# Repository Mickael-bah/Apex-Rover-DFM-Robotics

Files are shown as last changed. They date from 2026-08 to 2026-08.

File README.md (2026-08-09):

# Apex Rover — DFM & Robotics Engineering Project
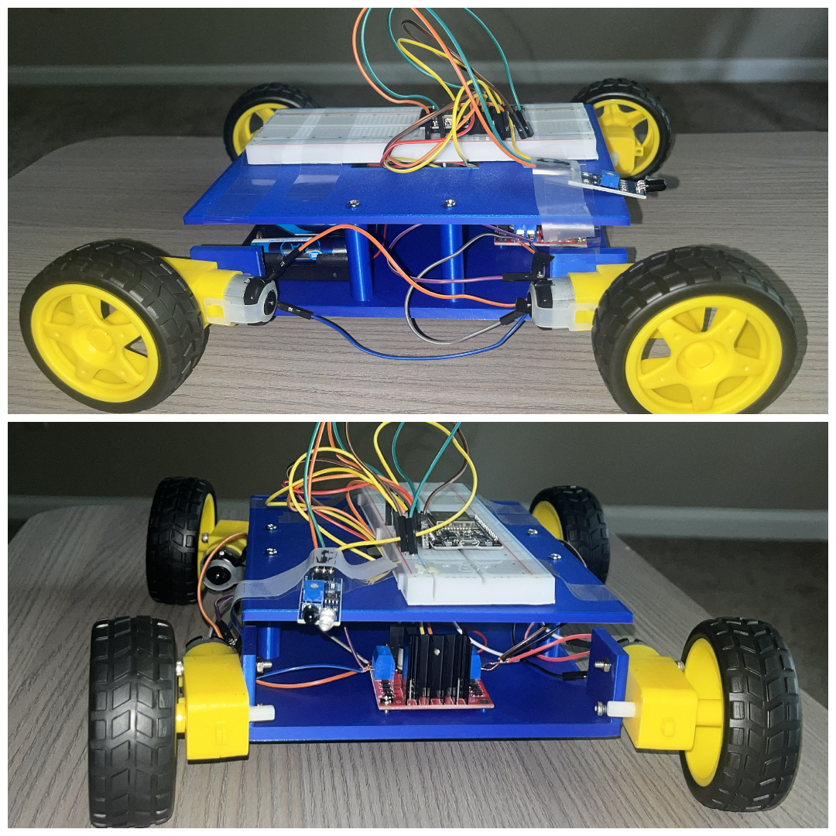
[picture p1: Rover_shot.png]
Apex Rover


https://github.com/user-attachments/assets/dc40459c-ff90-4590-9382-41a43c7b37aa

A custom 4WD robotic rover developed as a hands-on Design for Manufacturing (DFM), mechanical design, fabrication, electronics, and embedded robotics project.

## Project Overview

The Apex Rover is a 4WD skid-steer robotic vehicle built around a dual-deck 3D-printed chassis.

The rover has two operating modes:

- Wi-Fi manual control through an ESP32-hosted web interface
- Autonomous obstacle avoidance using infrared sensing

The main goal of this project was to experience the complete engineering process from CAD design to physical manufacturing, testing, and redesign.

## Engineering Objectives

This project was developed to gain practical experience in:

- Mechanical CAD design
- Design for Manufacturing (DFM)
- FDM 3D printing
- Engineering tolerances
- Fastener and joint design
- Mechanical assembly
- Electrical system integration
- ESP32 development
- Embedded C++
- Robotics control
- Physical prototype testing
- Engineering iteration

The primary objective was not simply to build a working rover, but to understand how a digital design behaves when converted into a physical manufactured prototype.

## Mechanical Design

The rover uses a two-level chassis architecture.

The lower chassis supports:

- Four TT gearbox motors
- Motor drive hardware
- Battery system
- High-current wiring

The upper deck supports:

- ESP32 controller
- Breadboard
- IR sensing hardware
- Control wiring

### Main Dimensions

| Parameter | Specification |
| --- | --- |
| Chassis footprint | 180 x 140 mm |
| Upper deck thickness | 3.5 mm |
| Deck separation | 40 mm |
| Fastener system | M3 |
| FDM infill | 20% gyroid |
| Primary materials | PLA / PETG |

## Design for Manufacturing

The chassis was designed specifically for FDM 3D printing.

Important DFM considerations included:

### Fastener Hole Tolerancing

M3 clearance holes were modeled at approximately 3.4 mm rather than the nominal 3.0 mm bolt diameter.

This provides clearance for the M3 fastener and accounts for the dimensional behavior of FDM printing.

### Structural Pillars

The lower chassis incorporates integrated 40 mm pillars supporting the upper deck.

This reduces the number of separate structural components and simplifies assembly.

### Cable Routing

A 60 x 40 mm cable pass-through opening was incorporated into the upper deck.

This allows motor and power wiring to pass between the two decks while keeping the wiring organized.

## V1 Prototype and Engineering Lessons

The physical prototype revealed several design considerations that were not fully apparent from CAD alone.

The most important observation was minor rotational movement at the pillar joints during high-torque skid turns.

This demonstrated the importance of positive mechanical retention in dynamically loaded joints.

The prototype also demonstrated the difference between clearance holes and threaded holes. A 3.4 mm M3 clearance hole allows a bolt to pass through, but it cannot provide a threaded connection by itself.

These observations were used to develop the V2 design.

## V1 to V2 Improvements

| V1 Observation | V2 Design Response |
| --- | --- |
| Pillar joint wobble | M3 heat-set brass inserts |
| Clearance holes cannot provide direct M3 threading | Dedicated self-tapping hole geometry |
| Nut accessibility | Recessed hex-nut pockets |
| Shared motor and logic power architecture | Dedicated 5 V logic regulator |

## Electronics

The rover is controlled by an ESP32.

Main components include:

- ESP32 NodeMCU
- L298N dual H-bridge motor driver
- Four TT gearbox motors
- IR obstacle detection system
- 6 x AA battery enclosure
- Breadboard
- M3 structural hardware

### ESP32 Motor Control

| ESP32 GPIO | Function |
| --- | --- |
| GPIO 26 | Left motor forward |
| GPIO 27 | Left motor reverse |
| GPIO 14 | Right motor forward |
| GPIO 12 | Right motor reverse |
| GPIO 33 | IR obstacle sensor input |

## Software

The firmware is written in C++ for the ESP32.

The rover hosts a local web interface through the ESP32 Wi-Fi access point.

Manual control uses HTTP endpoints for forward, backward, left, right, stop, automatic mode, and manual mode.

Autonomous operation uses a non-blocking state machine based on millis().

Major autonomous states include:

- DRIVING
- AVOID_STOPPING
- AVOID_REVERSING
- AVOID_PAUSING
- AVOID_TURNING
- PATROL_TURNING

### 🎮 Web Controller Interface

ESP32 Web Gamepad Interface

The ESP32 hosts an onboard HTTP REST server serving a responsive, dark-mode HTML5/CSS gamepad interface. It uses non-blocking JavaScript `fetch()` calls tied to touch events for zero-latency **Hold-to-Drive** safety control in landscape orientation.

## Manufacturing Workflow

The prototype followed this general engineering workflow:

1. Define requirements
2. Develop chassis architecture
3. Create CAD geometry
4. Apply DFM considerations
5. Manufacture the 3D-printed components
6. Assemble the mechanical system
7. Install electronics
8. Route and connect wiring
9. Upload and verify firmware
10. Test the physical prototype
11. Identify design limitations
12. Develop V2 improvements

## Repository Contents

- `Apex_Rover_DFM_Report_MB.pdf` - Complete DFM and technical report
- `apex_rover.ino` - ESP32 firmware
- `lower_chassis.step` - Lower chassis CAD model
- `lower_chassis.stl` - Lower chassis 3D-print file
- `top_deck.step` - Top deck CAD model
- `top_deck.stl` - Top deck 3D-print file
- `2D_technical_drawing.png` - Dimensioned technical drawing

## Lessons Learned

This project demonstrated that DFM is an iterative engineering process.

The workflow is not simply:

CAD -> Print -> Done

Instead, the physical prototype creates information that can be used to improve the next design:

Design -> Manufacture -> Test -> Learn -> Redesign

The project provided practical experience with manufacturing tolerances, mechanical joints, fastening strategies, assembly, cable management, electrical integration, and prototype evaluation.

## Project Status

V1 prototype: Complete and physically validated.

V2: Engineering improvements identified and documented.

The repository contains the V1 CAD models, manufacturing files, firmware, technical drawing, and DFM report.

## Author

Mickael Bah

Mechanical Engineering / Robotics

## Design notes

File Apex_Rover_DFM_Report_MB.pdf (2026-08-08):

# Apex Rover: Dual-Mode Wi-Fi & Autonomous Rover

Design for Manufacturing (DFM) & Technical Engineering Report

Author: Mickael Bah

Date: August 2026

Revision: 2.1 — Merged Portfolio Edition (DFM Process, Manufacturing Lessons & Reproducibility)

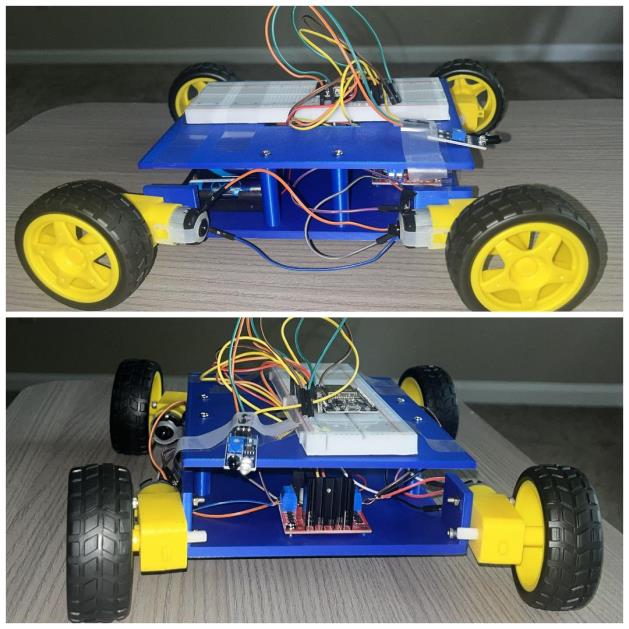
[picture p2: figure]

Figure 1.1: Completed Apex Rover hardware build featuring dual-deck 3D printed chassis and ESP32 control system.

Project purpose. This project was undertaken not only to produce a functional rover, but to gain hands-on experience with a complete engineering workflow: defining requirements, developing a manufacturable mechanical design, fabricating the parts, assembling and testing the physical prototype, identifying manufacturing/design weaknesses, and using those observations to develop a V2 design.

## 1. Executive Summary

The Apex Rover is a custom 4WD robotic vehicle built around a dual-deck 3D-printed chassis. It provides wireless manual control through an ESP32-hosted web interface, and an autonomous obstacle-avoidance mode using an active infrared sensor combined with a periodic patrol-turn pattern so the rover explores rather than driving in a single straight line. The mechanical system was intentionally developed as a practical Design for Manufacturing (DFM) exercise using FDM 3D printing and readily available hardware.

The engineering value of the project lies in the transition from CAD to a physical prototype. Manufacturing introduced real-world considerations that are difficult to fully predict in CAD, including printed-hole fit, joint rigidity, accessibility of fasteners, cable routing, and power-system behavior under combined electrical load. These observations were used to define specific V2 improvements.

The final design should be read as a validated V1 prototype rather than a claim of production-ready perfection. This report documents the design rationale, fabrication strategy, electrical architecture, assembly process, verification observations, and proposed V2 revisions — with enough pinout, wiring, and firmware detail that another builder could reproduce the prototype.

## 2. Design Requirements & Engineering Objectives

The following requirements define the engineering target for the prototype and provide a basis for evaluating whether individual design decisions serve the overall purpose of the rover.

Requirement | Target / Objective
Drive configuration | 4WD skid-steer
Operating modes | Wi-Fi manual control and autonomous obstacle avoidance
Mechanical manufacturing | FDM 3D printing for custom chassis components
Custom parts | Minimize the number of unique fabricated components
Chassis architecture | Two-level deck separating drive hardware from control electronics
Fasteners | Standard M3 hardware where practical
Chassis footprint | Approximately 180 mm x 140 mm
Deck separation | 40 mm integrated structural pillars
Design objective | Low-cost, reproducible prototype with accessible assembly
Learning objective | Experience the complete design -> manufacture -> test -> redesign cycle

## 3. Design Development & Concept Selection

The chassis architecture was developed around a practical manufacturing constraint: the rover needed to contain motors, battery/power hardware, the ESP32, breadboard, and sensors while remaining printable and easy to assemble. The final architecture uses two structural levels. The lower deck carries the higher-current drive hardware, while the upper deck carries the control electronics and sensor system.

Design logic: separating the two functional zones improves organization, protects the control electronics from the motor area, and creates a dedicated path for wiring between decks. The final chassis also keeps the number of custom printed components low — the primary fabricated structure consists of just two parts, P-01 and P-02.

This project should be understood as an iterative engineering process rather than a single CAD-to-print operation. The physical V1 prototype was used to expose limitations and inform the V2 design, detailed in Sections 9 and 10.

## 4. Bill of Materials & Manufactured Components

Category | Component | Specification / Qty | Purpose | Est. Unit Cost*
OTS | ESP32 NodeMCU | 30-pin, 3.3V logic, Soft-AP Wi-Fi, 1 | Control + web host | $6-10
OTS | L298N motor driver | Dual H-bridge, 2A peak, 1 | Motor power/control | $3-6
OTS | TT gearbox motors | 3V-6V DC, 1:48 ratio, 4 | 4WD propulsion | $1-2 ea.
OTS | IR obstacle module | Active IR transceiver, 1 (front-facing) | Obstacle detection | $1-3
OTS | Battery enclosure | 6x AA, 9V nominal series input, 1 | System power | $2-4

Category | Component | Specification / Qty | Purpose | Est. Unit Cost*
OTS | Solderless breadboard | 830-point dual rail grid, 1 | Signal distribution & bus grid | $3-5
OTS | M3 fasteners | M3x10 / M3x30, 12 | Structural mounting | $3-5 (set)
Printed | P-01 Top deck | 180x140x3.5 mm; 20% gyroid | Upper structure | filament only
Printed | P-02 Lower chassis | 180x140 mm; 40 mm pillars; 20% gyroid | Lower structure + pillars | filament only

## 5. DFM Strategy for FDM Manufacturing

The chassis was designed specifically for FDM manufacturing rather than treating 3D printing as a simple export step. The most important considerations were dimensional tolerance, fastener fit, joint design, printability, assembly access, and cable management.

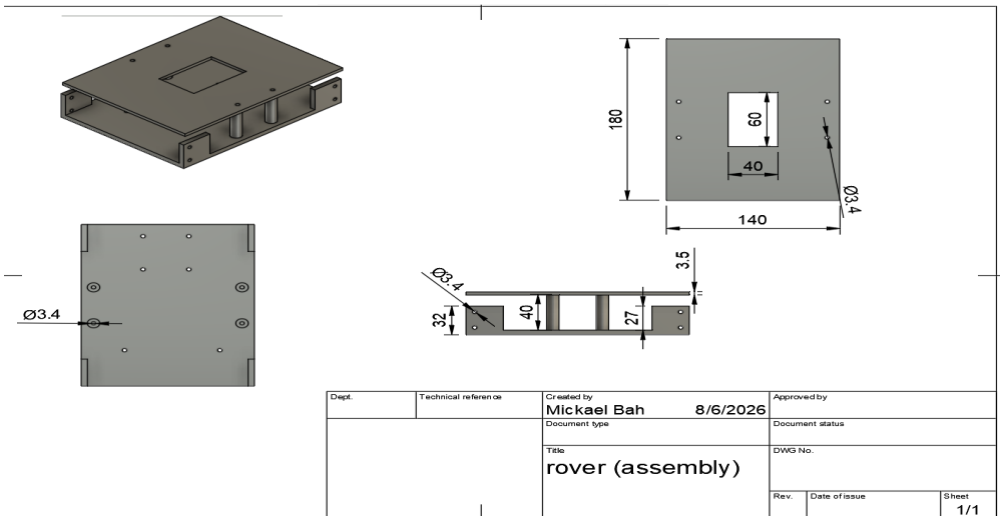
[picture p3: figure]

Figure 5.1: 2D dimensioned drawing sheet detailing deck plate dimensions (180 mm x 140 mm), 40 mm pillar heights, center cutout (60 mm x 40 mm), and Ø3.4 mm hole callouts.

## 5.1 Fastener Hole Tolerancing

M3 clearance holes were modeled at Ø3.4 mm rather than the nominal 3.0 mm bolt diameter. This provides clearance for the printed part and accounts for the dimensional behavior of FDM holes: inner diameters typically contract 0.1-0.2 mm during cooling. The resulting design allows the M3 bolt to pass through without binding. The V1 build confirmed that the clearance strategy works well for pass-through fastening, but also demonstrated that a clearance hole cannot itself provide a threaded connection without a nut or insert.

## 5.2 Structural Joint Design

The lower chassis incorporates 40 mm pillars to support the upper deck. This reduces the number of separate structural parts and simplifies assembly. However, the physical prototype showed minor rotational wobble at the pillar joints during high-torque skid turns. This is a useful DFM lesson: a geometry that is adequate for assembly in CAD can still require additional mechanical retention when subjected to dynamic loads.

## 5.3 Cable Management & Assembly Access

A 60x40 mm central cable aperture was incorporated into the upper deck to route motor and power wiring between the two decks. This feature reduces cable interference and keeps wiring organized without requiring additional printed cable-management components.

## 5.4 Material, Infill & Print Strategy

The documented V1 print strategy uses PLA or PETG at 20% gyroid infill. The final report records these settings as the validated baseline. Print-time, filament-mass, and cost measurements were not captured during the V1 build; these should be added from slicer history once available (see Appendix A).

## 6. Electrical Architecture & Wiring Matrix

The rover integrates mechanical, electrical, and software subsystems on a common ground bus and a single power rail distributing power from the battery enclosure to the motor driver, ESP32, and sensor.

## 6.1 Power Budget & Voltage Rationale

Design decision - why 9V instead of 6V:
The battery pack supplies all three subsystems in parallel off one rail: the L298N/motors, the ESP32, and the IR sensor. A 4xAA (6V) pack is sufficient for the TT motors alone, but once the ESP32's Wi-Fi radio (which draws current in bursts well above its average load during transmission) and the IR sensor share the same rail, the combined draw pulls the pack voltage down enough that the ESP32 browns out or resets mid-drive. The 6-cell (9V nominal) pack was chosen to keep enough headroom under combined load so the ESP32 stays powered through Wi-Fi transmit bursts. The tradeoff is that the motors (rated 3-6V) are run above their nominal rating.
- Motors run hotter and with reduced service life versus their 3-6V rating; acceptable for a prototype/demo.
- The L298N has its own onboard 5V regulator (enabled via the board's jumper) that derives logic-side 5V from the same input rail.
- V2 candidate fix: a dedicated 5V regulator feeding the ESP32 and IR sensor off a separate, current-limited tap — isolates the microcontroller from motor-induced voltage sag entirely rather than relying on pack headroom.

## 6.2 Wiring / Block Diagram

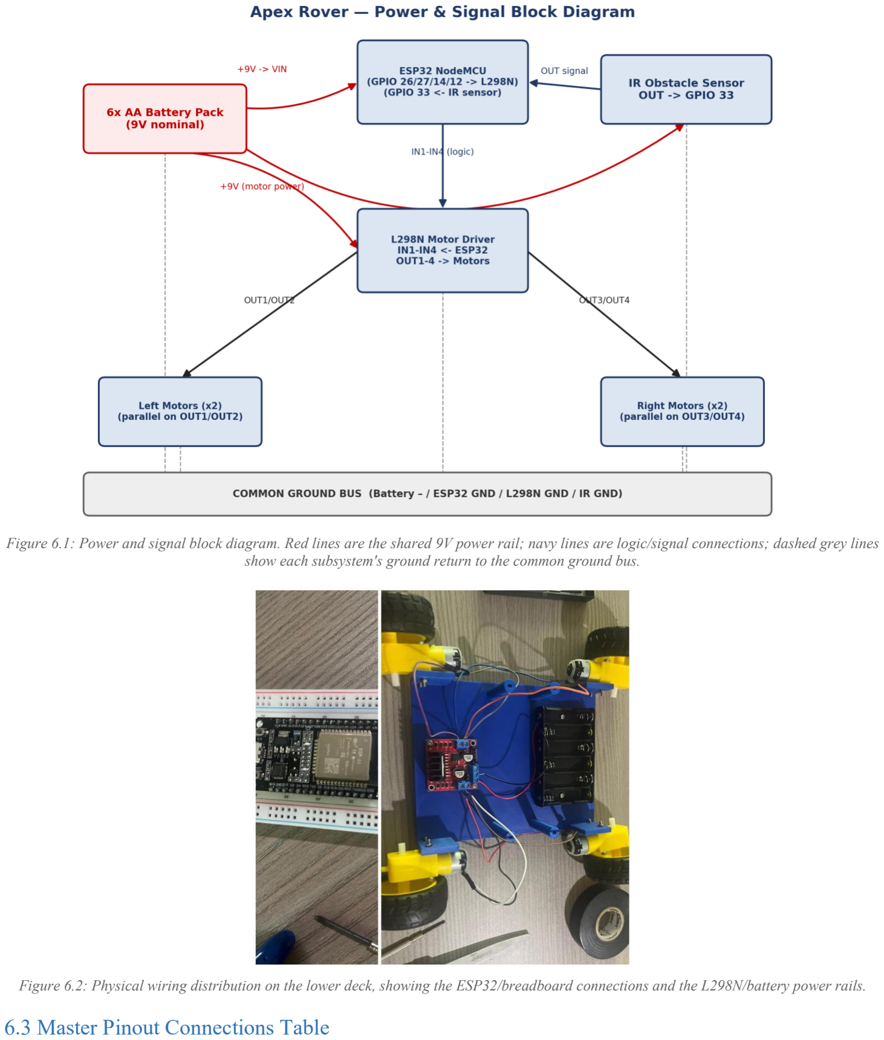
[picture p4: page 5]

Figure 6.1: Power and signal block diagram. Red lines are the shared 9V power rail; navy lines are logic/signal connections; dashed grey lines show each subsystem's ground return to the common ground bus.

Figure 6.2: Physical wiring distribution on the lower deck, showing the ESP32/breadboard connections and the L298N/battery power rails.

## 6.3 Master Pinout Connections Table

Source Device | Output Pin | Target Component | Input Pin | Wire Signal / Function
L298N Driver | OUT1 / OUT2 | Left Motors (Parallel) | Motor Terminals | Left Drive Output
L298N Driver | OUT3 / OUT4 | Right Motors (Parallel) | Motor Terminals | Right Drive Output
ESP32 | GPIO 26 | L298N Driver | IN1 | Left Motors Forward
ESP32 | GPIO 27 | L298N Driver | IN2 | Left Motors Reverse
ESP32 | GPIO 14 | L298N Driver | IN3 | Right Motors Forward
ESP32 | GPIO 12 | L298N Driver | IN4 | Right Motors Reverse
ESP32 | GPIO 33 | IR Sensor Module | OUT | Obstacle Signal Input
Breadboard Rail | GND (-) | ESP32 / L298N / IR | GND | Common Ground Bus
Breadboard Rail | RED (+) | ESP32 VIN / IR VCC | - | Common 9V Power Bus

## 7. Manufacturing & Assembly Process

The manufacturing workflow was intentionally organized as a reproducible sequence: fabricate the structural parts first, install the mechanical system, install the electronics, route wiring, then perform electrical and functional checks before final operation.

Stage | Process / DFM Consideration
1 | Print P-01 and P-02 using the documented 20% gyroid strategy.
2 | Install the four TT motors on the lower chassis; position left/right motor pairs symmetrically for skid-steer.
3 | Install the upper deck using M3 x 30 mm fasteners through the Ø3.4 mm clearance holes.
4 | Place the L298N near the motors to keep high-current wiring runs short.
5 | Mount ESP32, breadboard, and IR sensing hardware on the upper deck.
6 | Connect left and right motor pairs to the L298N outputs (OUT1/OUT2, OUT3/OUT4).
7 | Connect ESP32 control GPIOs to the L298N per the master pinout (Section 6.3).
8 | Connect the IR sensor and shared power/ground rails.
9 | Route power and signal wiring through the central 60x40 mm deck aperture.
10 | Power up with wheels off the ground and verify each direction command drives the correct motor the correct way before final operation.

## 8. Electrical & Software Integration

The ESP32 provides the control interface and hosts a Wi-Fi access point. Manual commands are sent through an HTML5 interface via JavaScript fetch() calls attached to ontouchstart/ontouchend events for Hold-to-Drive control, while autonomous operation uses a non-blocking state machine.

The documented firmware architecture includes DRIVING, AVOID_STOPPING, AVOID_REVERSING, AVOID_PAUSING, AVOID_TURNING, and PATROL_TURNING states. The use of millis()-based state transitions avoids blocking delay() calls, allowing the web interface to remain responsive during autonomous maneuvers.

## 8.1 Development Environment Setup

1. Install the Arduino IDE (2.x recommended).
2. Add the ESP32 board package: File > Preferences > Additional Boards Manager URLs, add: https://raw.githubusercontent.com/espressif/arduino-esp32/gh-pages/package_esp32_index.json
3. Tools > Board > Boards Manager: search "esp32" (Espressif Systems) and install.
4. Tools > Board: select the profile matching your NodeMCU-32S/ESP32 Dev Module variant.
5. No external libraries are required beyond the built-in WiFi.h that ships with the ESP32 board package.
6. Select the correct COM/serial port, set baud rate to 115200 to match Serial.begin(), and upload.

## 8.2 Web Interface

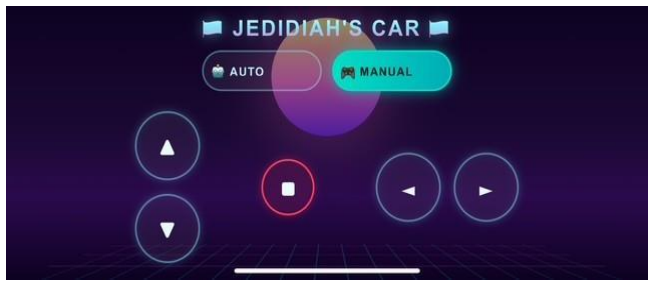
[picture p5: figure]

Figure 8.1: Web interface running in landscape mode, showing the AUTO/MANUAL mode toggle and Hold-to-Drive gamepad controls.

## 8.3 Firmware Source

The embedded control software is compiled using the Arduino ESP32 core. HTTP REST endpoints (/forward, /backward, /left, /right, /stop, /auto, /manual) drive both manual gamepad driving and state switching. A DEBUG_SENSOR flag prints raw IR transceiver readings to Serial to verify signal polarity and detection threshold during bring-up. The complete source code (apex_rover.ino) is maintained in the project repository referenced in Appendix B.

## 9. Physical Prototype Verification - V1

The most important verification result was not simply that the rover operated; it was that physical testing revealed design behavior that could be improved. These observations form the basis for the V2 engineering roadmap in Section 10.

Observed Result | Engineering Interpretation | Design Implication
Minor rotational wobble at pillar joints during high-torque skid turns | Friction-fit structural connection is not sufficiently rigid for dynamic loading | Use positive mechanical retention such as heat-set inserts
Ø3.4 mm holes provide easy M3 pass-through | Clearance-hole strategy is appropriate for bolt-through joints | Retain Ø3.4 mm for clearance applications; add nut/insert features where threading is needed
M3 machine screws cannot tap directly into Ø3.4 mm clearance holes | Clearance geometry and threaded geometry serve different functions | Use a smaller self-tapping profile or a separate insert/nut strategy
Motor and logic systems share one power architecture | Motor loads can create electrical disturbances or voltage sag | V2 should isolate logic power with a dedicated regulator

## 10. V1 → V2 Engineering Revision

The V2 roadmap is derived directly from the physical prototype. Each change is linked to an observed problem rather than being added only for complexity or appearance.

V1 Condition | Likely Cause / Lesson | V2 Revision
Pillar joint wobble | Friction-fit joint lacks positive retention under torque | M3 heat-set brass inserts in pillar tops
Clearance hole used where threading is desired | Ø3.4 mm is appropriate for clearance, not direct M3 thread formation | Ø2.8 mm self-tapping holes where appropriate
Nut access can complicate assembly | External nuts require tool access and can interfere with surfaces | 5.5 mm recessed hex-nut pockets
Logic and motor power share the system supply | Motor current can introduce voltage disturbances | Dedicated 5V regulator for ESP32 + IR sensor
Prototype documentation separate from controlled manufacturing files | Reproducibility requires a clear file/configuration baseline | Maintain revision-controlled CAD, drawings, BOM, and firmware manifest

## 11. Lessons Learned from the DFM Process

The primary objective of this project was hands-on exposure to the design-for-manufacturing cycle. Several practical lessons emerged from taking the design from CAD into a physical prototype:

- Nominal dimensions are not always manufacturing dimensions. FDM holes and interfaces require intentional tolerance design.
- CAD cannot replace physical validation. The pillar wobble was identified during operation rather than from the CAD model alone.
- Fastening strategy must be designed around the manufacturing process. Clearance holes, self-tapping holes, nuts, and threaded inserts solve different problems.
- Assembly is part of DFM. Cable access, fastener access, and component placement affect whether a design is practical to build and service.
- Prototype failures are design data. The V1 weaknesses became direct inputs to the V2 design rather than being treated simply as defects.
- Good DFM is iterative. The goal of the prototype was not to produce a perfect first iteration, but to learn how manufacturing behavior should influence the next design.

## 12. Conclusion

The Apex Rover successfully served as a hands-on Design for Manufacturing and robotics engineering project. The completed prototype demonstrates the integration of mechanical design, FDM fabrication, electrical wiring, embedded control, wireless communication, and autonomous behavior.

More importantly, the project provided direct experience with the transition from digital design to physical manufacturing. The V1 prototype exposed real limitations in joint rigidity, fastening strategy, and power architecture. These observations were converted into specific V2 design changes, including heat-set inserts, differentiated hole profiles, recessed nut pockets, and dedicated logic regulation.

The resulting design should be considered a validated V1 prototype with a documented path toward a more robust V2. The project demonstrates the engineering mindset required for DFM: design with manufacturing constraints in mind, build the part, test it under real conditions, learn from the result, and feed those lessons back into the next revision.

## Appendix A — Supplementary Engineering Deliverables

The following supplementary engineering assets accompany this documentation package:

- 2D Dimensioned Engineering Drawings (Figure 5.1 - Included)
- Chassis Part STL & STEP Files (P-01 & P-02)
- As-Built Wiring & Circuit Schematics (Figure 6.1 & 6.2 - Included)
- Smartphone Gamepad Interface Layout (Figure 8.1 - Included)

## Appendix B — Firmware Source

The embedded control software for the ESP32 is compiled using the standard Arduino IDE framework. The source code utilizes non-blocking state routines, HTTP REST endpoints, and an integrated HTML5/JavaScript gamepad engine.

- Primary Code File: apex_rover.ino
- Target Microcontroller: ESP32 NodeMCU / Dev Module
- Development Environment: Arduino IDE 2.x (Espressif ESP32 Core)
- Dependencies: WiFi.h (Standard ESP32 Built-in Library)

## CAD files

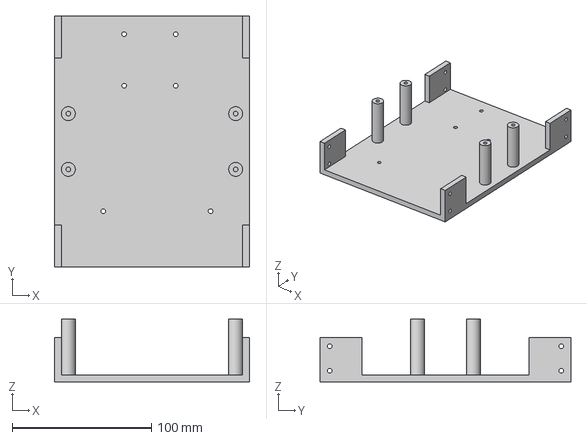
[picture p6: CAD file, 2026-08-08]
lower_chassis.step
140.0 x 180.0 x 45.0 mm

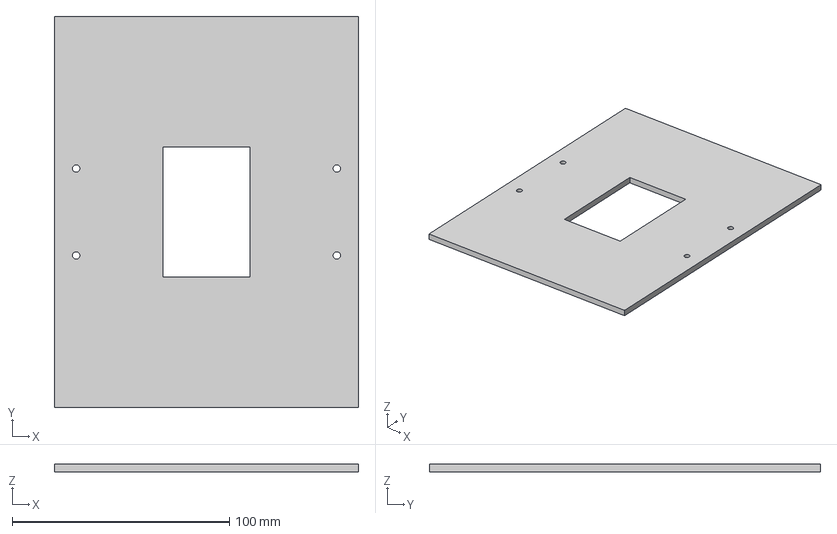
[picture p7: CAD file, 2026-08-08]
top_deck.step
140.0 x 180.0 x 3.50 mm

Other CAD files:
lower_chassis.stl
top_deck.stl

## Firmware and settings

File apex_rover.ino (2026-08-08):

#include <WiFi.h>

const char* ssid     = "JedidiahsCar";
const char* password = "password123";
WiFiServer server(80);

// ---- Motor Pins ----
const int IN1 = 26; // Left  Motors - Channel A
const int IN2 = 27; // Left  Motors - Channel B
const int IN3 = 14; // Right Motors - Channel A
const int IN4 = 12; // Right Motors - Channel B

// ---- Sensor Pin ----
const int IR_SENSOR_PIN = 33; // IR obstacle sensor (front-facing only)

// !!! DEBUG STEP !!!
// Most cheap IR obstacle modules are active-LOW (output goes LOW when
// something is close), but some are the opposite, and almost all of them
// have a small potentiometer on the board that sets detection range - out
// of the box that range is often far too short. Set DEBUG_SENSOR to true,
// upload, open Serial Monitor at 115200, and wave your hand in front of the
// sensor. You should see the printed value flip when an object gets close.
// If it never flips: adjust the pot. If it flips the "wrong" way: change
// OBSTACLE_ACTIVE_LEVEL below.
const bool DEBUG_SENSOR = true;
const int  OBSTACLE_ACTIVE_LEVEL = LOW; // level that means "something is close"

bool autoMode = false;

// ---- Autonomous avoidance tuning ----
const unsigned long REVERSE_MS          = 300;   // length of one reverse burst
const unsigned long TURN_MS             = 400;   // length of one turn burst
const unsigned long STOP_PAUSE_MS       = 100;   // brief pause between maneuver phases
const unsigned long REVERSE_COOLDOWN_MS = 4000;  // min time between reverse bursts
unsigned long lastReverseTime = 0;
bool nextTurnIsRight = true; // alternate so it doesn't spin one way forever

// ---- Patrol pattern tuning (turns every so often even with no obstacle) ----
const unsigned long PATROL_MIN_MS = 2000;
const unsigned long PATROL_MAX_MS = 4000;
unsigned long nextPatrolTurnAt = 0;

// ---- Autonomous state machine (non-blocking) ----
enum AutoState { DRIVING, AVOID_STOPPING, AVOID_REVERSING, AVOID_PAUSING, AVOID_TURNING, PATROL_TURNING };
AutoState autoState = DRIVING;
unsigned long stateStartedAt = 0;

void stopMotors();
void moveForward();
void moveBackward();
void turnLeft();
void turnRight();
void runAutonomousLogic();
void sendPage(WiFiClient &client);
bool obstacleDetected();
void enterAutoState(AutoState s);
unsigned long randomPatrolInterval();

void setup() {
  Serial.begin(115200);
  pinMode(IN1, OUTPUT);
  pinMode(IN2, OUTPUT);
  pinMode(IN3, OUTPUT);
  pinMode(IN4, OUTPUT);
  pinMode(IR_SENSOR_PIN, INPUT);
  stopMotors();

  WiFi.softAP(ssid, password);
  server.begin();
  Serial.println("Apex Rover Server Online");
}

void loop() {
  if (autoMode) {
    runAutonomousLogic();
  }

  WiFiClient client = server.available();
  if (client) {
    String request = "";
    while (client.connected()) {
      if (client.available()) {
        char c = client.read();
        request += c;
        if (c == '\n') {
          if (request.indexOf("GET /forward") >= 0)       { autoMode = false; moveForward(); }
          else if (request.indexOf("GET /backward") >= 0) { autoMode = false; moveBackward(); }
          else if (request.indexOf("GET /left") >= 0)     { autoMode = false; turnLeft(); }
          else if (request.indexOf("GET /right") >= 0)    { autoMode = false; turnRight(); }
          else if (request.indexOf("GET /stop") >= 0)     { autoMode = false; stopMotors(); }
          else if (request.indexOf("GET /auto") >= 0)     { autoMode = true; enterAutoState(DRIVING); }
          else if (request.indexOf("GET /manual") >= 0)   { autoMode = false; stopMotors(); }

          client.println("HTTP/1.1 200 OK");
          client.println("Content-type:text/html; charset=utf-8");
          client.println();
          sendPage(client);
          break;
        }
      }
    }
    client.stop();
  }
}

// ---------------------------------------------------------------------------
// Web interface
// ---------------------------------------------------------------------------
void sendPage(WiFiClient &client) {
  String modeButtons;
  if (autoMode) {
    modeButtons  = "<a class=\"mode-btn active-mode\" href=\"/auto\">&#129302; AUTO</a>";
    modeButtons += "<a class=\"mode-btn\" href=\"/manual\">&#127918; MANUAL</a>";
  } else {
    modeButtons  = "<a class=\"mode-btn\" href=\"/auto\">&#129302; AUTO</a>";
    modeButtons += "<a class=\"mode-btn active-mode\" href=\"/manual\">&#127918; MANUAL</a>";
  }

  String page = R"HTML(<!DOCTYPE html><html><head>
<meta charset="UTF-8">
<meta name="viewport" content="width=device-width, initial-scale=1.0, maximum-scale=1.0, user-scalable=no">
<style>
  html, body { height:100%; margin:0; padding:0; overflow:hidden; }
  body {
    font-family: 'Arial Black', Arial, sans-serif;
    background: linear-gradient(180deg, #0d0221 0%, #1a0933 45%, #2b0a4d 70%, #0d0221 100%);
    color:#eafcff;
    user-select:none; -webkit-user-select:none; touch-action:manipulation;
    display:flex; flex-direction:column; align-items:center; justify-content:center;
    position:relative;
  }
  .sun {
    position:fixed; top:6%; left:50%; transform:translateX(-50%);
    width:130px; height:130px; border-radius:50%; z-index:0; pointer-events:none; opacity:0.55;
    background: linear-gradient(180deg, #ffe66d, #ff6ec7 55%, #7b2ff7);
    box-shadow:0 0 60px 12px rgba(255,110,199,0.45);
  }
  .horizon {
    position:fixed; left:0; right:0; bottom:0; height:42%; z-index:0; pointer-events:none; opacity:0.55;
    background:
      repeating-linear-gradient(0deg, transparent 0 38px, rgba(255,60,200,0.4) 38px 40px),
      repeating-linear-gradient(90deg, transparent 0 38px, rgba(0,230,255,0.3) 38px 40px);
    transform: perspective(220px) rotateX(62deg);
    transform-origin: bottom;
    animation: gridScroll 1.1s linear infinite;
  }
  @keyframes gridScroll { from { background-position: 0 0, 0 0; } to { background-position: 0 40px, 40px 0; } }

  h1 {
    position:relative; z-index:1; font-size:24px; margin:4px 0 8px; letter-spacing:2px; text-transform:uppercase;
    background: linear-gradient(180deg, #ffffff, #7ee8fa 45%, #ff6ec7 100%);
    -webkit-background-clip:text; background-clip:text; color:transparent;
    text-shadow: 0 0 16px rgba(126,232,250,0.55);
  }
  .mode-container { position:relative; z-index:1; margin-bottom:12px; }
  .mode-btn {
    display:inline-block; width:120px; padding:9px 8px; margin:0 6px;
    font-size:13px; font-weight:bold; letter-spacing:1px; color:#bfefff; text-transform:uppercase;
    background:rgba(255,255,255,0.06); border:2px solid rgba(126,232,250,0.4);
    border-radius:999px; text-decoration:none;
  }
  .active-mode {
    background: linear-gradient(90deg,#00e0c6,#00adb5); color:#04211f; border-color:#00e0c6;
    box-shadow:0 0 16px rgba(0,224,198,0.6);
  }

  /* Shown only while the phone is upright - tells the driver to rotate it. */
  .rotate-hint { position:relative; z-index:1; display:none; flex-direction:column; align-items:center; gap:10px; padding:30px; }
  .rotate-hint .icon { font-size:56px; filter: drop-shadow(0 0 12px #7ee8fa); animation: spin 2.2s linear infinite; }
  @keyframes spin { to { transform:rotate(360deg); } }
  .rotate-hint p { font-size:15px; color:#bfefff; max-width:260px; }

  /* Two-thumb landscape controller - shown once the phone is turned sideways. */
  .gamepad { position:relative; z-index:1; display:none; justify-content:space-around; align-items:center; width:100%; max-width:520px; padding:10px; }
  .pad-column { display:flex; flex-direction:column; gap:15px; align-items:center; }
  .pad-row { display:flex; gap:15px; align-items:center; }
  .btn {
    width:76px; height:76px; line-height:76px; font-size:26px; font-weight:bold;
    color:#eafcff; background:rgba(255,255,255,0.05); border:2px solid rgba(126,232,250,0.5);
    border-radius:50%; outline:none;
    box-shadow: 0 0 10px rgba(126,232,250,0.25), inset 0 0 10px rgba(126,232,250,0.08);
    transition: transform 0.08s ease, box-shadow 0.08s ease, background 0.08s ease;
  }
  .btn:active {
    background: radial-gradient(circle, #00e0c6, #00838f); border-color:#00e0c6;
    transform:scale(0.9); box-shadow: 0 0 28px 6px rgba(0,224,198,0.8);
  }
  .btn-stop {
    width:62px; height:62px; line-height:62px; font-size:20px;
    background: rgba(255,60,90,0.12); border-color:#ff3c5a; box-shadow:0 0 10px rgba(255,60,90,0.35);
  }
  .btn-stop:active { background: radial-gradient(circle, #ff5a75, #b8103a); box-shadow:0 0 28px 6px rgba(255,60,90,0.85); }

  @media (orientation: portrait) {
    .rotate-hint { display:flex; }
    .gamepad, .mode-container { display:none; }
  }
  @media (orientation: landscape) {
    .rotate-hint { display:none; }
    .gamepad { display:flex; }
    .mode-container { display:block; }
  }
</style>
</head>
<body>
  <div class="sun"></div>
  <div class="horizon"></div>
  <h1>&#127937; Jedidiah's Car &#127937;</h1>

  <div class="rotate-hint">
    <div class="icon">&#8635;</div>
    <p>Flip it sideways (clockwise) to start racing!</p>
  </div>

  <div class="mode-container">MODE_BUTTONS_PLACEHOLDER</div>

  <div class="gamepad">
    <div class="pad-column">
      <button class="btn" ontouchstart="sendCmd('forward')" ontouchend="sendCmd('stop')" onmousedown="sendCmd('forward')" onmouseup="sendCmd('stop')">&#9650;</button>
      <button class="btn" ontouchstart="sendCmd('backward')" ontouchend="sendCmd('stop')" onmousedown="sendCmd('backward')" onmouseup="sendCmd('stop')">&#9660;</button>
    </div>
    <div><button class="btn btn-stop" onclick="sendCmd('stop')">&#9632;</button></div>
    <div class="pad-row">
      <button class="btn" ontouchstart="sendCmd('left')" ontouchend="sendCmd('stop')" onmousedown="sendCmd('left')" onmouseup="sendCmd('stop')">&#9668;</button>
      <button class="btn" ontouchstart="sendCmd('right')" ontouchend="sendCmd('stop')" onmousedown="sendCmd('right')" onmouseup="sendCmd('stop')">&#9658;</button>
    </div>
  </div>

  <script>
    function sendCmd(cmd) { fetch('/' + cmd); }
  </script>
</body></html>)HTML";

  page.replace("MODE_BUTTONS_PLACEHOLDER", modeButtons);
  client.print(page);
}

// ---------------------------------------------------------------------------
// Autonomous obstacle avoidance + patrol pattern (non-blocking state machine)
// ---------------------------------------------------------------------------
bool obstacleDetected() {
  int reading = digitalRead(IR_SENSOR_PIN);
  if (DEBUG_SENSOR) {
    Serial.print("IR_SENSOR_PIN raw reading: ");
    Serial.println(reading);
  }
  return reading == OBSTACLE_ACTIVE_LEVEL;
}

unsigned long randomPatrolInterval() {
  return PATROL_MIN_MS + random(0, (long)(PATROL_MAX_MS - PATROL_MIN_MS));
}

void enterAutoState(AutoState s) {
  autoState = s;
  stateStartedAt = millis();
}

void runAutonomousLogic() {
  unsigned long now = millis();
  unsigned long elapsed = now - stateStartedAt;

  switch (autoState) {

    case DRIVING:
      // Path is (as far as we know) clear - keep rolling forward.
      moveForward();

      if (obstacleDetected()) {
        stopMotors();
        enterAutoState(AVOID_STOPPING);
        break;
      }

      // No obstacle - but every so often, turn anyway just to wander
      // instead of driving in one straight line forever.
      if (nextPatrolTurnAt == 0) nextPatrolTurnAt = now + randomPatrolInterval();
      if (now >= nextPatrolTurnAt) {
        stopMotors();
        enterAutoState(PATROL_TURNING);
      }
      break;

    case PATROL_TURNING:
      if (elapsed == 0) { // first tick in this state
        if (nextTurnIsRight) turnRight(); else turnLeft();
        nextTurnIsRight = !nextTurnIsRight;
      }
      if (elapsed >= TURN_MS) {
        stopMotors();
        nextPatrolTurnAt = now + randomPatrolInterval();
        enterAutoState(DRIVING);
      }
      break;

    case AVOID_STOPPING:
      if (elapsed >= STOP_PAUSE_MS) {
        // The IR sensor only looks forward, so cap how often we're willing
        // to back up blind. If we reversed recently, skip straight to
        // turning instead of reversing again immediately.
        if (now - lastReverseTime > REVERSE_COOLDOWN_MS) {
          enterAutoState(AVOID_REVERSING);
        } else {
          enterAutoState(AVOID_TURNING);
        }
      }
      break;

    case AVOID_REVERSING:
      if (elapsed == 0) moveBackward();
      if (elapsed >= REVERSE_MS) {
        stopMotors();
        lastReverseTime = now;
        enterAutoState(AVOID_PAUSING);
      }
      break;

    case AVOID_PAUSING:
      if (elapsed >= STOP_PAUSE_MS) {
        enterAutoState(AVOID_TURNING);
      }
      break;

    case AVOID_TURNING:
      if (elapsed == 0) {
        if (nextTurnIsRight) turnRight(); else turnLeft();
      }
      if (elapsed >= TURN_MS) {
        stopMotors();
        nextTurnIsRight = !nextTurnIsRight;
        nextPatrolTurnAt = now + randomPatrolInterval();
        enterAutoState(DRIVING);
      }
      break;
  }
}

// ---------------------------------------------------------------------------
// Motor primitives
// ---------------------------------------------------------------------------
void stopMotors() {
  digitalWrite(IN1, LOW); digitalWrite(IN2, LOW);
  digitalWrite(IN3, LOW); digitalWrite(IN4, LOW);
}

// Rev 1.3: swapped again - forward/backward were still reversed on the
// physical rover. This pattern is now confirmed correct.
void moveForward() {
  digitalWrite(IN1, LOW);  digitalWrite(IN2, HIGH);
  digitalWrite(IN3, HIGH); digitalWrite(IN4, LOW);
}
void moveBackward() {
  digitalWrite(IN1, HIGH); digitalWrite(IN2, LOW);
  digitalWrite(IN3, LOW);  digitalWrite(IN4, HIGH);
}

// Rev 1.3: swapped again - left/right were still reversed on the
// physical rover. This pattern is now confirmed correct.
void turnLeft() {
  digitalWrite(IN1, HIGH); digitalWrite(IN2, LOW);
  digitalWrite(IN3, HIGH); digitalWrite(IN4, LOW);
}
void turnRight() {
  digitalWrite(IN1, LOW);  digitalWrite(IN2, HIGH);
  digitalWrite(IN3, LOW);  digitalWrite(IN4, HIGH);
}
